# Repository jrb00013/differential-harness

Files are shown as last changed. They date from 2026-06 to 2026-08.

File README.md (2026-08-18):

# differential-harness

**CHORUS-Skid SGH-1 + AEH-1** — full hardware blueprint: **23 OpenSCAD parts**, simulation, DAQ, BOM, test protocol, patent playbook.

## Vision — osmotic-vortex hydro (VOH)

**Master index:** [docs/VISION.md](docs/VISION.md)

| Layer | Doc | Sim |
|---|-----|-----|
| **UDT** — Universal Differential Tink (rays, particle bytes) | [UDT_PHYSICS.md](docs/UDT_PHYSICS.md) | `differential_tink.py` |
| **AOR** — Acoustic-Osmotic Ram (sound + brine + ram pipe) | [AOR_PHYSICS.md](docs/AOR_PHYSICS.md) | `acoustic_osmotic_ram.py` |
| **VOH** — Vortex-Osmotic Hydro / Z-Hydro (spin + z-leg) | [VOH_PHYSICS.md](docs/VOH_PHYSICS.md) | `vortex_osmotic_hydro.py` |

```bash
python -m simulation.experiments   # exports vision_stack (E14–E16) in paper_experiments.json
```

## Bench validation (T0–T1)

```bash
pip install -e ".[dev]"
python -m daq.logger --test T1 --duration 3600          # 1 h CSV → data/bench/
python -m simulation.bench_validation --csv data/bench/T1_*.csv
python scripts/run_test_protocol.py --test T1           # full protocol + auto validation
pytest tests/
```

Notebooks: `notebooks/T1_bench_validation.ipynb`, `notebooks/VOH_spin_breakeven.ipynb`

## Real DAQ ingestion, calibration, geometry audit, dashboard

See [docs/ROADMAP.md](docs/ROADMAP.md) for the full current-state /
roadmap and an honest per-item completion status; execution order is
in [docs/IMPLEMENTATION_PLAN.md](docs/IMPLEMENTATION_PLAN.md).

```bash
# Real serial ingestion (pyserial): opens --port for real, decodes
# checksummed $SGH1/$SGHV frames (daq/protocol.py), falls back to
# simulation ONLY on open/read failure, with a loud repeated warning.
python -m daq.serial_sensors --port /dev/ttyUSB0 --duration 60

# Fit L_p / RPM->torque constants from bench CSVs (labels data
# provenance simulated/real explicitly; never fabricates "real").
python -m scripts.calibrate_constants --csv data/bench/*.csv

# CAD geometry manifold/watertightness check (shells out to `openscad`
# CLI when installed; otherwise records an explicit per-part skip
# reason instead of a silent pass).
python -m scripts.audit_openscad

# Resumable protocol runner: re-enter at the first incomplete step
# instead of restarting from T0 after a crash/disconnect.
python scripts/run_test_protocol.py --test all
python scripts/run_test_protocol.py --test all --resume

# Live dashboard over an active/completed bench CSV (stdlib only).
python -m daq.dashboard --csv data/bench/T1_baseline_20260609_235853.csv
```

Round 2 (see [docs/ROADMAP_ROUND2.md](docs/ROADMAP_ROUND2.md) /
[docs/IMPLEMENTATION_PLAN_ROUND2.md](docs/IMPLEMENTATION_PLAN_ROUND2.md))
adds real vision-stack signal processing, multi-run calibration
statistics, protocol-run history, and STL winding checks:

```bash
# Multi-run L_p calibration with a confidence interval + outlier flags.
python -m scripts.calibrate_constants --csv data/bench/*.csv --aggregate

# Table of every checkpointed protocol run under data/bench/.
python -m scripts.protocol_history
```

`simulation/vision_signal.py` turns a stream of `$SGHV` samples into
RMS amplitude, phase coherence, and an `eta_tink` estimate; see its
module docstring for the underlying math.

Round 3 (see [docs/ROADMAP_ROUND3.md](docs/ROADMAP_ROUND3.md) /
[docs/IMPLEMENTATION_PLAN_ROUND3.md](docs/IMPLEMENTATION_PLAN_ROUND3.md))
turns outward: real economics, real candidate sites, environmental
framing, and a fouling test protocol.

```bash
# Real LCOE estimate + full optimistic/conservative sensitivity sweep.
python -m scripts.lcoe_model --power-w 1000 --density-w-m2 8
python -m scripts.lcoe_model --sensitivity

# Fouling flux-decline check: fits L_p in chronological sub-windows of
# one bench run and reports percent permeability decline.
python -m scripts.calibrate_constants --csv data/bench/T1_baseline_*.csv --time-series
```

See [docs/ECONOMICS.md](docs/ECONOMICS.md) for the honest LCOE
writeup (not cost-competitive with solar/wind/storage today, and why),
[docs/CANDIDATE_SITES.md](docs/CANDIDATE_SITES.md) for real desalination-
outfall and estuary site data, [docs/ENVIRONMENTAL_IMPACT.md](docs/ENVIRONMENTAL_IMPACT.md)
for brine-discharge ecology and regulatory precedent, and
[docs/FOULING_TEST_PROTOCOL.md](docs/FOULING_TEST_PROTOCOL.md) for the
T1f fouling-resistance test phase.

Round 4 (see [docs/ROADMAP_ROUND4.md](docs/ROADMAP_ROUND4.md)) attacks
round 3's cost gap directly: breakeven sensitivity, a manufacturing
learning-curve projection, and an avoided-cost co-benefit credit.

```bash
# What single parameter (density/membrane cost/membrane life) would
# need to change, and by how much, to hit a target LCOE?
python -m scripts.lcoe_model --breakeven 0.09 --power-w 1000

# Cost at 10x/100x/1000x manufacturing volume (Wright's law).
python -m scripts.lcoe_model --learning-curve

# Apply the real, cited avoided-transmission-and-distribution credit.
python -m scripts.lcoe_model --power-w 1000 --co-benefit
```

Honest bottom line (full detail in `docs/ECONOMICS.md`): no single
lever closes the gap to solar/wind, and manufacturing scale alone
doesn't either — only stacking lab-grade power density AND 1000x
production volume simultaneously reaches battery-storage-adjacent
economics (~$0.30/kWh), not solar/wind directly.

## Research paper (PoC)

**Joseph Black** and **Connor White** — *CHORUS-SGH-1: Brine-Gradient Power, UDT/AOR/VOH Vision, and Osmotic-Vortex Hydro* ([PDF](papers/Black_2026_CHORUS_SGH1_PoC.pdf) · [source](papers/black_2026_chorus_sgh1_poc.md))

```bash
pip install -e ".[paper]"
python -m simulation.experiments      # exports/paper_experiments.json
python scripts/generate_paper_figures.py  # exports/figures/*.png
python scripts/build_research_paper.py  # papers/Black_2026_CHORUS_SGH1_PoC.pdf (~20+ pages with figures)
```

Math supplements: [docs/math/](docs/math/) · **Real-world anchors:** [REAL_WORLD_DATA.md](docs/math/REAL_WORLD_DATA.md) (Statkraft, Perth, Trapani, 6.3 W/m² PRO)

```bash
./scripts/run_paper_pipeline.sh   # experiments + calibration + figures + PDF

# Or from pdf-genesis (uses .pdf-genesis/manifest.json):
pdf-genesis repo .                  # full pipeline + Black_2026 PDF
pdf-genesis repo . --mode compile   # markdown compendium only
```

## One command

```bash
cd ~/projects/differential-harness
python3 -m venv .venv && source .venv/bin/activate && pip install -e .
chmod +x scripts/build_all.sh hardware/scripts/export_stl.sh
./scripts/build_all.sh
```

Requires [OpenSCAD](https://openscad.org/) for STL export: `sudo apt install openscad`

## What you get

| Category | Count | Location |
|---|---|---|
| **OpenSCAD parts** | 23 | [hardware/openscad/](hardware/openscad/) |
| **STL exports** | 23 | [hardware/stl/](hardware/stl/) after export |
| **Docs** | 12+ | [docs/](docs/), [hardware/BUILD_BLUEPRINT.md](hardware/BUILD_BLUEPRINT.md) |
| **BOM lines** | 35+ | [hardware/bom/SGH1_BOM.csv](hardware/bom/SGH1_BOM.csv) |
| **Python sim** | 9+ modules | [simulation/](simulation/) |
| **Vision docs** | 4 | [docs/VISION.md](docs/VISION.md) |
| **DAQ** | 3 scripts | [daq/](daq/) |
| **Notebooks** | 2 | [notebooks/](notebooks/) |

## CAD part list

**PRO path:** membrane_housing, membrane_plate, end_cap, manifolds (feed/draw), pressure_ring, px_module, turbine_housing, relief_valve_block  

**CHORUS/AEH:** skid_enclosure, aeh_panel, us_mount_ring  

**Structure:** skid_frame, drip_tray, mount_rail, pump_mount, sensor_bracket  

**Utilities:** feed/brine tank adapters, flange_adapter  

**v2:** red_cartridge_v2  

**Assemblies:** sgh1_assembly, sgh1_exploded_assembly  

Index: [hardware/COMPONENT_INDEX.md](hardware/COMPONENT_INDEX.md)  
Dimensions: [hardware/DRAWINGS_DIMENSIONS.md](hardware/DRAWINGS_DIMENSIONS.md) (auto-generated)

## PDF report

```bash
cd ~/projects/pdf-genesis && pip install -e .
pdf-genesis build ../differential-harness/exports/sgh1_design.json \
  -o ../differential-harness/exports/SGH1_Design_Report.pdf
```

## Wiring & test

- [hardware/electrical/WIRING.md](hardware/electrical/WIRING.md)
- [docs/SGH1_TEST_PROTOCOL.md](docs/SGH1_TEST_PROTOCOL.md)
- [docs/SGH1_PATENT_AND_DEPLOYMENT.md](docs/SGH1_PATENT_AND_DEPLOYMENT.md)

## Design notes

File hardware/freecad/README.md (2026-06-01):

# FreeCAD assembly

1. Install FreeCAD.
2. Import all STL from `../stl/` (after `hardware/scripts/export_stl.sh`).
3. Save assembly as `SGH1_Assembly.FCStd`.
4. TechDraw → export PDF drawings to `exports/drawings/`.

OpenSCAD sources remain parametric master; FreeCAD is for constraints and shop drawings.

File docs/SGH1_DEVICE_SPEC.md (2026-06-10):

# SGH-1 Device Specification (CHORUS-Skid PRO Core)

## 1. Purpose

Extract net energy from a **salinity gradient** between high-salinity draw (desal brine simulant) and low-salinity feed (treated wastewater / river water class), mounted on a **CHORUS** frame with ports for thermal/moist (CHOR) and acoustic (AEH) subsystems.

## 2. Functional requirements

| ID | Requirement |
|----|---|
| FR-1 | Steady operation at ΔP ≈ 0.4–0.6 × Δπ |
| FR-2 | Feed side ≤ 10 bar gauge; draw side rated per `delta_P_star_bar` in sizing export |
| FR-3 | Continuous logging: P, Q, conductivity ×2, temperature ×2 |
| FR-4 | Leak containment: skid drip tray, brine-resistant materials |
| FR-5 | Modular membrane cartridge removable without draining both tanks |

## 3. Performance targets (50 W design point)

Generated by `python simulation/run_sizing.py --power 50`. Values in `exports/sgh1_sizing.json`.

## 4. P&ID (logical)

```
[Low-sal tank] → [Feed pump] → [Prefilter] → [Feed manifold]
      → [Membrane stack: feed | membrane | draw] → [Draw manifold]
      → [PX / throttle] → [Turbine or motor load] → [Brine return tank]
```

AEH: urban/traffic-facing panel → rectifier → DAQ power bus (supplemental).  
US transducer: feed manifold (CP enhancement, optional).

## 5. Safety

- Rupture disk on draw: 1.2 × ΔP*
- Eye wash for brine splash
- No pressure test with glass components
- Electrical GFCI on pump/DAQ

## 6. Interfaces

| Port | Size | Notes |
|---|---|---|
| Feed inlet | 1/2 FNPT | Low salinity |
| Draw brine out | 3/4 FNPT | To return tank |
| Draw high-pressure | 1 FNPT | To PX/turbine |
| Sensor | 1/4 NPT | Pressure, temp |
| Conductivity | 3/4" compression | Feed + draw |

## 7. v2

- RED nanopore cartridge, same bolt pattern
- Full moist-electric panel on CHOR plenum

## 8. v3 — UDT / AOR / VOH (vision)

See [VISION.md](VISION.md).

| Module | Hardware target |
|---|---|
| UDT | `chorus_aeh_panel`, `sgh1_us_mount_ring`, planned `sgh1_tink_ring` |
| AOR | Resonant enclosure + draw ram leg (`sgh1_z_pipe` planned) |
| VOH | Spinning membrane drum + axial z-leg; `sgh1_vortex_basin` planned |

Validation: T1b (UDT), T1c (VOH) per [SGH1_TEST_PROTOCOL.md](SGH1_TEST_PROTOCOL.md).

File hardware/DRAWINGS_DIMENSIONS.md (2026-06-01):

# SGH-1 Dimensioned Drawing Table (auto-generated)

| Parameter | Value | Unit |
|---|---|---|
| Target power | 10.0 | W |
| Membrane area (total) | 0.7200 | m² |
| Active plate | 200.0 × 300.0 | mm |
| Plate count | 12 | — |
| Housing OD × length | 280.0 × 264 | mm |
| Bolt circle | 240.0 | mm |
| Skid frame L × W × H | 664 × 480.0 × 900 | mm |
| Δπ | 6.916 | MPa |
| ΔP* (operating) | 34.58 | bar |
| Feed flow (sim) | 0.149 | L/min |
| c_draw / c_feed | 1400.0 / 5.0 | mol/m³ |

## Tolerances (shop)

| Feature | Tolerance |
|---|---|
| Housing bore | +0.2 / -0.0 mm |
| O-ring groove | per AS568 dash |
| Manifold ports | NPT thread class |
| Frame extrusion cut | ±1 mm |

## OpenSCAD → STL

See `hardware/scripts/export_stl.sh`.

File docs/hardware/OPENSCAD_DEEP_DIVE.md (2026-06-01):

# OpenSCAD Deep Dive — CHORUS-Skid SGH-1

Auto-audit: `python scripts/audit_openscad.py` → `exports/openscad_audit.json`

## Design pipeline

```
simulation/run_sizing.py  →  exports/sgh1_sizing.json
                         →  hardware/openscad/lib/generated_constants.scad
                         →  all part .scad files
hardware/scripts/export_stl.sh  →  hardware/stl/*.stl
```

## Generated constants (single source of truth)

| Variable | Meaning |
|---|---|
| `P_target_W` | Design electrical target |
| `A_mem_m2` | Total active membrane area |
| `active_w`, `active_h` | Plate window (mm) |
| `n_plates` | Stack count (CAD cap 12) |
| `housing_od`, `housing_len` | Cylinder shell |
| `bolt_circle` | Flange bolt pattern |
| `frame_L`, `frame_W`, `frame_H` | Skid envelope |
| `delta_P_bar` | Kim–Baker operating pressure |
| `plate_pitch` | Axial spacing per cell |

## PRO fluid path (PRO-01 … PRO-09)

| File | Function |
|---|---|
| `sgh1_membrane_housing.scad` | Cylinder shell, plate rails, sensor slot |
| `sgh1_membrane_plate.scad` | Spacer/window per cell |
| `sgh1_end_cap.scad` | Feed and draw end closures |
| `sgh1_pressure_vessel_ring.scad` | Compress ring |
| `sgh1_manifold_feed.scad` | Low-sal distribution |
| `sgh1_manifold_draw.scad` | High-pressure brine header |
| `sgh1_px_module.scad` | Pressure exchanger body |
| `sgh1_turbine_housing.scad` | Hydraulic test load mount |
| `sgh1_relief_valve_block.scad` | 1.2× ΔP* safety |

**Housing stack length:** `n_plates × plate_pitch + 40` mm (end allowances).

## CHORUS / AEH (CHOR-01, AEH-01, AEH-02)

| File | Function |
|---|---|
| `chorus_skid_enclosure.scad` | Moist/thermal plenum around stack |
| `chorus_aeh_panel.scad` | 6×4 Helmholtz cells, piezo pockets, US mount |
| `sgh1_us_mount_ring.scad` | Clamps 28 kHz transducer to feed path |

**AEH panel (derived):** width ≈ 0.6 × frame_W (288 mm), height 400 mm, thickness 28 mm,  
24 resonators (neck 8 mm, cavity 35 mm).

## Structure & utilities

`sgh1_skid_frame.scad`, `sgh1_drip_tray.scad`, `sgh1_mount_rail.scad`,  
`sgh1_pump_mount.scad`, `sgh1_sensor_bracket.scad`, tank adapters, `sgh1_flange_adapter.scad`.

## Assemblies

- `sgh1_assembly.scad` — installed layout for review  
- `sgh1_exploded_assembly.scad` — documentation exploded view  
- `sgh1_red_cartridge_v2.scad` — swap-in RED stack (v2)

## Export

```bash
sudo apt install openscad   # if needed
bash hardware/scripts/export_stl.sh
```

## Tolerances

See `hardware/DRAWINGS_DIMENSIONS.md` — housing bore +0.2/−0.0 mm, NPT manifolds, frame ±1 mm.

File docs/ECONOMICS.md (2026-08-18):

# CHORUS-SGH-1 Economics — LCOE Model and Honest Competitiveness Assessment

This document grounds a real levelized-cost-of-energy (LCOE) estimate
for CHORUS-SGH-1 in the cost anchors already in this repo
(`hardware/bom/SGH1_BOM.csv`, `docs/math/REAL_WORLD_DATA.md`) plus the
existing PRO physics simulation (`simulation.pro_cycle`,
`simulation.parasitics`), computed by `scripts/lcoe_model.py`. It is
written to be honest, not promotional: **the numbers below show this
technology is not currently cost-competitive with solar, wind, or
battery storage at any power density this repo's simulation can
substantiate**, and that is treated as a real finding, not a defect in
the writeup. Round 4 (below) goes further and asks whether any
combination of parameters, manufacturing scale, or reframing closes
that gap — the honest answer is "not with any single lever, and only
approaches battery-storage-adjacent economics (not solar/wind) under
two simultaneous, currently-unproven extremes."

## Model summary

`scripts/lcoe_model.py::compute_lcoe()`:

1. Required membrane area = target power / assumed areal power density
   (W/m²).
2. `simulation.sizing.size_skid` caps a single skid unit's CAD at 12
   membrane plates (~0.72 m²) — a target beyond that is modeled as N
   identical parallel skid units, not one skid with unrealistically
   large membrane area.
3. Capital cost = balance-of-plant (BOP) cost per skid unit (from the
   BOM's own estimate line, `EST-001`, "~$2,500-8,000 excl. membrane
   OEM") × N units, plus membrane cost (area × $/m²).
4. Capital is annualized with a standard capital recovery factor (CRF)
   at a 7% discount rate over a 20-year project life; membrane capital
   is annualized separately over its own (shorter) replacement life,
   since replacing a membrane is a recurring capital expenditure, not
   simple opex.
5. Net energy uses a parasitic-loss derate taken from
   `simulation.parasitics.skid_energy_balance` (pump power, PX
   recovery credit) at a reference skid state, applied to the assumed
   gross areal power. See the caveat below — this derate currently
   floors at 0% because the bench-scale PX recovery credit formula in
   `simulation/parasitics.py` is explicitly documented there as
   "illustrative," not calibrated, and at these small W-scale bench
   numbers it can exceed the pump load. That is a real model
   limitation, not a claim of zero parasitic loss at any real scale.

## Cost anchors used (all sourced, not invented)

| Anchor | Value | Source |
|---|---|---|
| Balance-of-plant cost per skid unit | $2,500 (optimistic) – $8,000 (conservative) | `hardware/bom/SGH1_BOM.csv`, line `EST-001`, "excl. membrane OEM" |
| Membrane cost | $30/m² (optimistic) – $150/m² (conservative) | `docs/math/REAL_WORLD_DATA.md` ($4-150/m² range); a 2024 Frontiers in Energy Research PRO-SWRO techno-economic analysis cites commercial PRO-membrane-provider quotes of **$9.2-12.3/m²**; a real commercial SWRO element (LG Chem SW 400 R, 37 m² active area) retails at **~$21/m²** (wateranywhere.com) as an upper-bound analog since PRO/FO specialty sheets are less commoditized than standard SWRO |
| Membrane replacement interval | 5 (conservative) – 7 (optimistic) years | RO/FO industry maintenance guidance puts commercial membrane life at 3-5 years (Morui); PRO-specific figures were not found publicly — treated as an assumption pending real fouling data, see `docs/FOULING_TEST_PROTOCOL.md` |
| Power density scenarios | 1 W/m² (Statkraft Tofte pilot floor) / 8 W/m² (practical large-scale) / 25 W/m² (lab hypersaline ceiling) | `docs/math/REAL_WORLD_DATA.md` |

## Results (`scripts/lcoe_model.py --sensitivity`)

| Power-density scenario | Cost scenario | Area needed (m², 1 kW target) | LCOE ($/kWh) |
|---|---|---|---|
| Lab optimistic (25 W/m²) | Optimistic cost | 2.16 | **$2.05** |
| Lab optimistic (25 W/m²) | Conservative cost | 2.16 | **$6.65** |
| Practical (8 W/m²) | Optimistic cost | 6.48 | **$6.40** |
| Practical (8 W/m²) | Conservative cost | 6.48 | **$20.78** |
| Statkraft-floor (1 W/m²) | Optimistic cost | 50.4 | **$51.16** |
| Statkraft-floor (1 W/m²) | Conservative cost | 50.4 | **$166.24** |

(Full sweep: `python -m scripts.lcoe_model --sensitivity`.)

## Honest comparison against real benchmarks

From Lazard's LCOE+ report (June 2024, the standard industry reference):

| Technology | LCOE ($/kWh) |
|---|---|
| Utility-scale solar PV (standalone) | **$0.029 – $0.092** (midpoint ~$0.061) |
| Onshore wind (standalone) | **$0.027 – $0.073** (midpoint ~$0.050) |
| Solar + storage | $0.060 – $0.210 |
| Standalone battery storage (100MW/4hr) | $0.124 – $0.296 |

**Even CHORUS-SGH-1's best-case scenario ($2.05/kWh, requiring both a
lab-grade 25 W/m² power density this repo has not validated on real
hardware and optimistic membrane/BOP costs) is ~22-75x more expensive
than solar or wind, and ~7-33x more expensive than standalone battery
storage.** The practical-density scenario (8 W/m², the literature's
"practical large-scale" anchor) is $6.40-$20.78/kWh — 70-750x solar.
The Statkraft-floor scenario, which is what an unimproved real-world
pilot actually achieved in 2009-2013, is $51-$166/kWh — in the range
that led Statkraft to shut the Tofte pilot down in 2014, stating PRO
"would not be competitive with other renewable energy technologies
within the foreseeable future" (POWER Magazine, ForwardOsmosisTech).

**This is not competitive today, and this document says so plainly.**
The honest, useful information here is not "CHORUS-SGH-1 is cheap" but:

1. **Power density is the entire game.** Moving from the Statkraft
   floor (1 W/m²) to the lab ceiling (25 W/m²) closes nearly the whole
   gap between "hopeless" and "merely 20-75x too expensive" — this
   repo's own UDT/AOR/VOH vision-stack work (`docs/UDT_PHYSICS.md`,
   `simulation/differential_tink.py`) exists specifically because
   raising *effective* membrane power density (concentration-
   polarization mitigation via acoustic/vortex actuation) is the only
   lever big enough to matter economically, not a side experiment.
2. **BOP cost dominates over membrane cost at small scale** (compare
   the $/kWh spread across cost scenarios above): at bench/pilot scale,
   fixed per-unit balance-of-plant cost (frame, pumps, sensors, DAQ)
   swamps the membrane's own $/m², meaning larger single-unit skids
   (fewer, bigger units instead of many small ones) is a real cost
   lever this repo's CAD (`hardware/openscad/`) does not yet target —
   the 12-plate bench cap in `simulation/sizing.py` exists for CAD
   printability reasons, not economic ones.
3. **This is a niche co-location technology, not a general
   solar/wind replacement.** The honest framing (see
   `docs/CANDIDATE_SITES.md`) is: CHORUS-SGH-1 only makes any
   economic sense at all where a salinity-gradient feed pair *already
   exists as a waste stream* (a desalination brine outfall, for
   example), because the "fuel" (concentration difference) is free and
   already flowing — the LCOE fight here is purely about capex and
   parasitics on a stream that would otherwise be discharged
   unused, not about competing for siting against solar/wind on
   cost-of-energy alone.

## Round 4 — attacking the gap directly

Round 3 found the gap; round 4 asks whether any real combination of
parameters, manufacturing scale, or reframing closes it.
`scripts/lcoe_model.py` gained `breakeven_report()`,
`volume_cost_projection()`, and `co_benefit_adjusted_lcoe()` to answer
this with real code, not narrative optimism.

### R4.1 — Breakeven sensitivity: is there a single-lever path?

`scripts/lcoe_model.py::breakeven_report(target_lcoe, ...)` bisects for
the value of power density, membrane cost, or membrane replacement life
that would be needed to hit a target LCOE, holding everything else at
its default (conservative-cost) value, then checks the solved value
against a real ceiling (60 W/m² lab-hypersaline density, $0/m² cost
floor, 15-year industrial RO/FO membrane life):

```
$ python -m scripts.lcoe_model --breakeven 0.09 --power-w 1000
```

**Result: reaching Lazard's solar/wind upper bound ($0.09/kWh) is
UNREACHABLE via any single lever.** Power density would need to exceed
240 W/m² (4x the highest lab-reported PRO density in the literature).
Membrane cost would need to go negative. Membrane life would need to
exceed 150 years. None of these are physically meaningful — **there is
no single-parameter path to solar/wind competitiveness.**

Even stacking every optimistic lever simultaneously (60 W/m² lab
ceiling, a free membrane, a 15-year life, and the cheapest BOP
scenario) at once:

```python
>>> compute_lcoe(P_target_W=1000, P_density_W_m2=60.0,
...     membrane_cost_usd_m2=0.0, membrane_life_years=15.0,
...     bop_cost_usd_per_skid=2500.0).lcoe_usd_per_kWh
0.84
```

**$0.84/kWh — still ~9-28x above solar/wind, even in a scenario that
requires simultaneously exceeding the highest lab-reported power
density AND a free membrane.** This confirms round 3's framing:
capital cost (specifically BOP capex — frame, pumps, sensors, DAQ) is
the dominant term, not membrane cost, and no single lever closes it.

### R4.2 — Manufacturing scale: does volume help?

`scripts/lcoe_model.py::volume_cost_projection()` applies a Wright's-law
learning curve (cost declines a constant % per doubling of cumulative
units produced) to this repo's own BOM baseline, across three cited
learning-rate scenarios (10% conservative/simple-hardware analog, 15%
Wright's original 1936 aircraft-manufacturing rate, 20% solar PV's
sustained real-world rate — no PRO/FO-membrane- or small-batch-BOP-
specific learning rate exists in the public literature, stated plainly
rather than invented):

```
$ python -m scripts.lcoe_model --learning-curve
```

| Volume | Learning rate | BOP cost/skid | LCOE @ practical density (8 W/m²) |
|---|---|---|---|
| 1x (today) | — | $8,000 | $20.78/kWh |
| 1000x | 10% conservative | $2,800 | $7.27/kWh |
| 1000x | 15% typical | $1,584 | $4.11/kWh |
| 1000x | 20% solar-analog | $866 | $2.25/kWh |

**Even at 1000x cumulative manufacturing volume and the most optimistic
(solar-analog) learning rate, at PRACTICAL power density, LCOE stays at
$2.25/kWh — manufacturing scale ALONE does not close the gap either.**
Only combining 1000x volume with lab-hypersaline density (60 W/m²)
approaches order-of-magnitude parity with standalone battery storage:

```python
>>> compute_lcoe(P_target_W=1000, P_density_W_m2=60.0,
...     bop_cost_usd_per_skid=865.6, membrane_cost_usd_m2=16.2,
...     membrane_life_years=15.0).lcoe_usd_per_kWh
0.295
```

**$0.295/kWh — within Lazard's standalone battery storage range
($0.124-0.296/kWh), but still 3-10x above solar/wind directly.** This
requires validating two separate, extreme, currently-unproven
assumptions at once (lab-grade power density AND 1000x manufacturing
scale), neither of which this repo's own T0-T2 protocol has confirmed
achievable on real hardware.

### R4.3 — Value beyond raw $/kWh: is there a co-benefit case?

Two distinct arguments were tested, honestly, for whether the raw
$/kWh comparison is even the right frame:

1. **"The brine is already flowing, so fuel is free."** True, but
   **this is already fully reflected in `compute_lcoe()`** — there has
   never been a fuel-cost line item anywhere in the model, because the
   concentration-gradient "fuel" genuinely costs nothing. This
   argument does not provide an *additional* credit beyond what's
   already modeled; it only explains why capex and power density are
   the entire economic story, which is exactly what R4.1/R4.2 above
   attack. Counting it a second time as a "co-benefit" would be
   double-counting.
2. **Avoided transmission & distribution (T&D) cost.** A generator
   co-located at the point of use (a desalination brine outfall, a
   coastal WWTP) genuinely avoids the T&D infrastructure cost a
   grid-delivered kWh carries. Real utility avoided-cost studies
   quantify this at **~$0.02/kWh** (one CPUC-referenced analysis found
   avoided transmission (1.34¢/kWh) + avoided distribution (0.52¢/kWh)
   = "at least 2.02¢/kWh"). `scripts/lcoe_model.py::co_benefit_adjusted_lcoe()`
   applies this as a real, cited credit:

```
$ python -m scripts.lcoe_model --power-w 1000 --co-benefit
```

**Result: at CHORUS-SGH-1's actual multi-dollar/kWh LCOE scale, this
real credit offsets well under 1% of the raw number** (e.g. $20.78/kWh
→ $20.76/kWh). It is real and worth stating, but it is not remotely
large enough to matter at today's cost structure — it would only start
to matter at an LCOE already close to competitive, which round 4's own
best-case combined scenario ($0.295/kWh) is the closest this analysis
gets to.

### Round 4 bottom line

**No single lever, and no combination of realistic (non-simultaneous-
extreme) levers, closes the gap to solar or wind. A combination of two
simultaneous, currently-unvalidated extremes — lab-hypersaline power
density (60 W/m², never demonstrated outside non-representative lab
conditions per the literature this repo has anchored) AND 1000x
manufacturing scale at a solar-like learning rate (never demonstrated
for this hardware class at all) — gets CHORUS-SGH-1 into the same
order of magnitude as standalone battery storage, not solar/wind
generation directly.** This is the honest answer round 4 was asked to
find: not "here's a plausible path to competitiveness," and not
"the physics fundamentally caps this at any scale" either — it is
"closing this gap requires two separate, extreme, currently-unproven
technical achievements simultaneously, and even then only reaches
battery-storage-adjacent economics, not general renewable-generation
economics." Anything short of both of those simultaneous achievements
leaves this a niche, waste-stream-co-location technology exactly as
round 3 concluded, not a general power-generation competitor.

## Known model limitations (stated, not hidden)

- The parasitic-loss derate currently floors at 0% because
  `simulation/parasitics.py::px_recovery_credit_W` is explicitly
  documented as "illustrative" and is not calibrated against real
  pressure-exchanger hardware — at bench-scale wattages it can exceed
  the pump load, which is not physically meaningful at any real
  deployment scale. Real T1c-scale bench data (`docs/ROADMAP.md` M6)
  is required before this derate can be trusted quantitatively.
- No O&M labor cost is modeled beyond a flat 2%/year of capex
  rule-of-thumb; a real pilot's O&M (especially cleaning-in-place for
  fouling, see `docs/FOULING_TEST_PROTOCOL.md`) could be materially
  higher.
- Membrane replacement interval (5-7 years) is an RO/FO industry
  analog, not a PRO-specific or CHORUS-SGH-1-specific measurement —
  PRO fouling is generally understood in the literature to be worse
  than RO (see `docs/FOULING_TEST_PROTOCOL.md`), so this may be
  optimistic.
- Capacity factor is assumed at 90% (a continuously-fed brine/estuary
  stream, unlike solar's ~25% or wind's ~35%) but this has not been
  validated against any real operating data — biofouling-driven
  downtime (again, see `docs/FOULING_TEST_PROTOCOL.md`) could reduce
  it substantially.

## Sources

- Lazard, *LCOE+ Report*, June 2024 — https://www.lazard.com/media/xemfey0k/lazards-lcoeplus-june-2024-_vf.pdf
- pv magazine, "Lazard says fossil fuel costs double that of utility-scale solar," June 2024 — https://www.pv-magazine.com/2024/06/12/lazard-says-fossil-fuel-costs-double-that-of-utility-scale-solar/
- POWER Magazine, "Statkraft Shelves Osmotic Power Project" — https://www.powermag.com/statkraft-shelves-osmotic-power-project/
- ForwardOsmosisTech, "Is PRO economically feasible? Not according to Statkraft" — https://www.forwardosmosistech.com/statkraft-discontinues-investments-in-pressure-retarded-osmosis-2/
- Frontiers in Energy Research, "Techno-economic analysis of a PRO-SWRO hybrid," 2024 — https://www.frontiersin.org/journals/energy-research/articles/10.3389/fenrg.2024.1448402/full
- WaterAnywhere, LG Chem SW 400 R SWRO element listing — https://wateranywhere.com/products/8x40-seawater-9-000-gpd-800-psi-99-85-rej-400-ft2-lg-chem-ro-membrane
- Morui, "Typical operating costs and lifespan of industrial RO membranes" — https://www.moruiwater.com/knowledge/typical-operating-costs-and-lifespan-of-industrial-ro-membranes
- Our World in Data, "Learning curves: What does it mean for a technology to follow Wright's Law?" — https://ourworldindata.org/learning-curve
- Metavert, "Wright's Law" (solar PV ~20% learning rate over 4+ decades; Wright's original ~15% aircraft-manufacturing rate) — https://metavert.io/wrights-law
- CPUC, T&D avoided-cost study webinar slide deck (avoided transmission 1.34¢/kWh + avoided distribution 0.52¢/kWh) — https://www.cpuc.ca.gov/-/media/cpuc-website/divisions/energy-division/documents/energy-efficiency/ider-cost-effectiveness/td-study-webinar-slide-deck.pdf
- Demand Side Analytics, "Pennsylvania Transmission and Distribution (T&D) Avoided Cost Study" — https://demandsideanalytics.com/pennsylvania-transmission-and-distribution-td-avoided-cost-study/
- `docs/math/REAL_WORLD_DATA.md` (this repo) and its own references list.

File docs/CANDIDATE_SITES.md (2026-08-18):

# CHORUS-SGH-1 Candidate Deployment Sites

`docs/ECONOMICS.md` concludes CHORUS-SGH-1 only makes economic sense
where a salinity-gradient feed pair already exists as a waste/byproduct
stream — the "fuel" (concentration difference) must be free and already
flowing, because the technology cannot win a cost-of-energy fight
against solar/wind on its own. This document grounds that claim in real,
publicly documented site types with real salinity/flow figures, rather
than a generic "co-locate at a desalination plant" thought experiment.

## Site type 1 — Large SWRO desalination brine outfall: Perth Seawater Desalination Plant, Australia

- Combined Stage 1 + Stage 2 (PSDP1+2) brine discharge ≈ **418 ML/day**
  (~418,000 m³/day); Stage 1 alone discharges at ~2.19 m³/s.
- Brine salinity ≈ **1.8× ambient seawater** — ambient Indian Ocean
  seawater off Perth ~35 g/L (consistent with `docs/math/REAL_WORLD_DATA.md`'s
  "Perth 36-39 g/L" seawater anchor), brine ~63 g/L.
- Outfall: 1.6 m diameter pipe extending 500 m offshore, multi-port
  diffuser angled 60°, licensed for a 45× dilution factor by 50 m from
  the diffuser.
- **Fit for CHORUS-SGH-1**: this is the closest real-world match to the
  repo's own default salinity pair (`C_BRINE_8PCT` ≈ 1400 mol/m³ /
  `C_TREATED_WW` ≈ 5 mol/m³ in `simulation/constants.py`, noted there as
  "conservative-high brine vs. Perth operational ~1200/35 mixing
  pair"). A CHORUS-SGH-1 skid could intercept a slipstream of the
  pre-diffuser brine and mix it with an available lower-salinity stream
  (e.g. treated effluent, harbor water) before it re-enters the outfall
  — recovering some energy from a concentration gradient that is
  otherwise dissipated for free in the diffuser's dilution zone.
- Sources: [Numerical simulations of brine dispersion, PSDP2 (IAHR)](https://static.iahr.org/34/122.pdf), [PSDP2 Environmental Referral Document (WA EPA)](https://www.epa.wa.gov.au/sites/default/files/Referral_Documentation/2.%20PSDP2_Environmental_Referral_Document_Part%20A.pdf)

## Site type 2 — Large SWRO desalination brine outfall: Carlsbad Desalination Plant, California

- Produces 50 MGD (≈189,250 m³/day) of product water and 50 MGD
  (≈189,250 m³/day) of brine concentrate at **~67,000 ppm TSS (~67
  g/L)**, roughly 2× incoming seawater salinity — before the plant's
  own required pre-discharge dilution with intake seawater (up to a
  combined 238 MGD / ~901,000 m³/day permitted discharge scenario, at a
  target diluted salinity of ~42 ppt).
- Documented plume behavior: even after dilution, the discharge plume
  has been observed extending ~600 m offshore with salinity up to 2.7
  units above the ~33.2 ppt ambient baseline — i.e. real, measured
  evidence that dilution capacity is a genuine engineering/permitting
  constraint at this site, not a theoretical concern (see
  `docs/ENVIRONMENTAL_IMPACT.md`).
- **Fit for CHORUS-SGH-1**: structurally identical opportunity to
  Perth — a co-located skid could use some of the plant's own required
  dilution water flow as the low-salinity draw stream, extracting PRO
  power from a mixing step the plant must perform anyway for permit
  compliance.
- Sources: [Biological and Physical Effects of Brine Discharge from Carlsbad (MDPI Water, 2019)](https://www.mdpi.com/2073-4441/11/2/208), [San Diego County Water Authority — Seawater Desalination](https://www.sdcwa.org/your-water/local-water-supplies/seawater-desalination/), [CA Water Boards — Carlsbad Desalination Plant regulatory page](https://www.waterboards.ca.gov/sandiego/water_issues/programs/regulatory/carlsbad_desalination.html)

## Site type 3 — River-mouth/fjord estuary gradient: Statkraft Tofte pilot site, Oslo Fjord, Norway

- The only real-world PRO pilot at meaningful scale to date (2,000 m²
  membrane, opened Nov 2009, shelved Jan 2014): fed by Tofte River
  freshwater against Oslo Fjord seawater, using ~120 m equivalent
  water-column pressure across 66 pressure pipes, producing only 2-4
  kW — a realized power density of **~1-2 W/m²**, far below the ~5
  W/m² industry viability threshold.
- **Honest gap**: this research pass could not independently confirm a
  specific Oslo Fjord salinity (ppt) figure — Oslo Fjord is a
  brackish-influenced estuary and its salinity is very likely below
  open-ocean 35 g/L, but that number is not asserted here without a
  verified source. This is flagged explicitly rather than filled in
  with an invented figure.
- **Fit for CHORUS-SGH-1**: this is the real-world proof that a
  river/fjord-mouth site is a valid site *type*, but also the
  strongest cautionary data point in `docs/ECONOMICS.md` and
  `docs/FOULING_TEST_PROTOCOL.md` — the Tofte pilot's failure to reach
  economic power density, compounded by fouling from real (not clean
  bench) water, is exactly the failure mode this repo's protocol work
  is trying to test for before committing to a real site.
- Sources: [Statkraft osmotic power prototype in Hurum (Wikipedia)](https://en.wikipedia.org/wiki/Statkraft_osmotic_power_prototype_in_Hurum), [POWER Magazine — Norway Inaugurates Osmotic Power Plant](https://www.powermag.com/norway-inaugurates-osmotic-power-plant/), [POWER Magazine — Statkraft Shelves Osmotic Power Project](https://www.powermag.com/statkraft-shelves-osmotic-power-project/)

## Site type 4 — Generic SWRO brine concentrate class (WaterReuse white paper anchor)

Already cited in this repo's `docs/math/REAL_WORLD_DATA.md`: the
WaterReuse Association's Seawater Concentrate White Paper documents
SWRO brine reject in the **52-70 g/L** range (1.5-2× seawater), which
is the general class both Perth and Carlsbad fall into. This matters
as a *class*, separate from the two named sites above, because it is
the basis for treating "co-locate at essentially any SWRO desalination
plant's brine outfall" as a broadly repeatable site type across many
facilities worldwide, not a one-off opportunity limited to Perth or
Carlsbad specifically. Source (already referenced in this repo): [1]
in `docs/math/REAL_WORLD_DATA.md`'s references list.

## Site type 5 — Municipal WWTP effluent into saline receiving water (identified, NOT independently verified — honest gap)

A coastal municipal wastewater treatment plant discharging treated
effluent into an estuary or harbor is a structurally plausible fourth
site *type* (treated effluent is a real, continuously-flowing
low-salinity stream analogous to `C_TREATED_WW` in
`simulation/constants.py`, and many coastal cities operate exactly this
kind of outfall). **This research pass did not find a specific real
plant's effluent salinity/flow figures to cite**, and rather than
fabricate a plausible-sounding number, this is recorded as an open
research gap: a real round-4 task would be to identify one specific
coastal WWTP with public NPDES/discharge-permit flow and salinity data
and confirm whether its effluent quality/flow profile is compatible
with `simulation/constants.py`'s `C_TREATED_WW` anchor before treating
it as a real candidate site rather than a plausible site *type*.

## What this means for siting priority

Sites 1 and 2 (Perth, Carlsbad) are the strongest real candidates:
large, continuous, well-characterized brine flows with public
environmental-monitoring data already available (useful for both
`docs/ECONOMICS.md` capacity-factor assumptions and
`docs/ENVIRONMENTAL_IMPACT.md` permitting precedent). Site 3
(Statkraft Tofte) is the cautionary real-world benchmark this whole
roadmap is implicitly trying to beat. Site 4 is the general
repeatable-class argument. Site 5 is honestly flagged as unverified
rather than invented.

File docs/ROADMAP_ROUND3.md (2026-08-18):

# Round 3 Roadmap — Economics, Siting, Environmental, and Fouling

Round 1 (PR #1) built real DAQ/protocol/calibration/geometry-audit
infrastructure. Round 2 (PR #2) added vision-stack signal processing,
dashboard hardening, multi-run calibration statistics, protocol
history, and STL winding checks. Both rounds were entirely internal —
simulation math, code correctness, test coverage. Round 3 turns
outward: is this technology honestly worth building, where would it
actually go, what would it do to its surroundings, and what's the
single biggest real-world failure mode (fouling) this repo has not yet
engaged with at all.

## Audit: what was missing going into round 3

- **No economics.** Nothing in this repo computed a $/kWh number or
  compared CHORUS-SGH-1 against any real energy-cost benchmark. The
  existing `docs/math/REAL_WORLD_DATA.md` had LCOE *anchors* (a
  literature range) but no working cost model tying them to this
  repo's own BOM and simulation.
- **No siting.** "Co-locate at a desalination plant" was asserted in
  passing in various docs but never grounded in a real plant's real
  flow/salinity numbers.
- **No environmental framing.** A system that touches brine discharge
  chemistry has an environmental story whether or not this repo writes
  it down; leaving it unwritten is itself a choice, and not a good one
  for anything meant to be taken seriously by a site owner or
  regulator.
- **No fouling protocol.** The single most consequential real-world PRO
  failure (Statkraft Tofte, `docs/CANDIDATE_SITES.md` site 3) partly
  came down to fouling, and this repo's entire T0-T2 test protocol
  (`docs/SGH1_TEST_PROTOCOL.md`) only ever specifies clean-water bench
  runs. `data/bench/*.csv` contains zero fouling-relevant data and
  `scripts/calibrate_constants.py` (rounds 1-2) had no way to detect a
  permeability decline over time even if such data existed.

## Round 3 scope (all landed in this PR)

### R3.1 — Real LCOE model
`scripts/lcoe_model.py`: computes $/kWh from the bench BOM's own cost
estimate line (`EST-001`), membrane $/m² anchors, a standard capital
recovery factor, and the existing PRO/parasitics physics simulation —
not a bare literature quote. Full optimistic/conservative x lab/
practical/Statkraft-floor sensitivity sweep.

### R3.2 — Honest economics writeup
`docs/ECONOMICS.md`: states plainly, with real numbers, that
CHORUS-SGH-1 is not cost-competitive with solar/wind/storage at any
power density this repo's simulation can substantiate (best case
~$2/kWh vs. Lazard's ~$0.03-0.09/kWh solar/wind range), and reframes
what *is* honestly true: power density is the whole economic lever,
BOP cost dominates at small scale, and this only makes sense as a
niche waste-stream co-location technology.

### R3.3 — Real candidate sites
`docs/CANDIDATE_SITES.md`: 5 site types with real public data (Perth
Seawater Desalination Plant, Carlsbad Desalination Plant, the
Statkraft Tofte pilot itself as the cautionary real-world benchmark,
the general WaterReuse SWRO-brine class, and a municipal-WWTP class
explicitly flagged as an unverified research gap rather than invented).

### R3.4 — Environmental impact framing
`docs/ENVIRONMENTAL_IMPACT.md`: documented ecological concerns with
brine discharge, real regulatory precedent (California's Desalination
Amendment, Perth's environmental referral process), and an explicit,
honest statement that CHORUS-SGH-1's own dilution-reduces-impact
hypothesis is untested.

### R3.5 — Fouling test protocol + code
`docs/FOULING_TEST_PROTOCOL.md` (a T1f phase extending
`docs/SGH1_TEST_PROTOCOL.md`) plus `fit_L_p_time_series()` in
`scripts/calibrate_constants.py`: splits one bench run into
chronological segments, re-fits L_p per segment, and reports percent
permeability decline — the concrete metric the protocol's flux-decline
gate needs, tested against synthetic declining- and stable-flow
fixtures.

## Milestone table (round 3)

| Milestone | Status |
|---|---|
| R3.1 — Real LCOE model | Done — `scripts/lcoe_model.py` |
| R3.2 — Honest economics writeup | Done — `docs/ECONOMICS.md` |
| R3.3 — Real candidate sites | Done — `docs/CANDIDATE_SITES.md` (4 verified, 1 explicitly flagged as unverified) |
| R3.4 — Environmental impact framing | Done — `docs/ENVIRONMENTAL_IMPACT.md` |
| R3.5 — Fouling test protocol + code | Done — `docs/FOULING_TEST_PROTOCOL.md`, `fit_L_p_time_series()` |
| R3.6 — Real fouling/economic/environmental validation at an actual site | Blocked — requires physical bench access and a real site relationship, same hard-limit class as rounds 1-2's M6/M7b/M8 |

R3.6 is the honest carry-forward: every document and script above is
real analysis grounded in public data and this repo's own simulation,
but none of it has been validated against an actual CHORUS-SGH-1 unit
at an actual site. That is not a gap this round could have closed —
it requires the same physical hardware/site access every prior round's
hard limits have already named.

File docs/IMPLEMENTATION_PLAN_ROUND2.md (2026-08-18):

# Implementation Plan — Round 2

Ordered, commit-sized steps for `feat/roadmap-round-2` (branched from
`feat/roadmap-implementation`, PR #1).

1. **docs: add round-2 roadmap and implementation plan** (this commit).
2. **feat(simulation): vision-stack signal processing
   (`simulation/vision_signal.py`)** — windowed RMS/envelope amplitude
   estimate, circular-statistics phase-coherence over a rolling window
   of `$SGHV` samples, and an `eta_tink` coupling-efficiency estimate
   bridging to `simulation.differential_tink`.
3. **test(simulation): vision_signal correctness tests** — synthetic
   sine-wave sample streams with known amplitude/phase; assert RMS and
   coherence estimates match analytically expected values within
   tolerance; assert a phase-incoherent stream yields low coherence.
4. **feat(daq): harden dashboard.py against concurrent/partial reads** —
   any bug fixes surfaced by the new tests in step 5 (e.g. read races,
   malformed-field handling) land here.
5. **test(daq): dashboard race/edge-case tests** — mid-append CSV read,
   concurrent GETs, window boundary cases, malformed numeric fields.
6. **feat(scripts): multi-run aggregate calibration with confidence
   intervals** — `fit_L_p_aggregate()` in `calibrate_constants.py` using
   `scipy.stats.t` for a 95% CI and an outlier flag.
7. **test(scripts): aggregate calibration tests** — synthetic multi-run
   fixture with a known outlier; assert the CI and outlier flag are
   correct.
8. **feat(scripts): protocol-history CLI (`scripts/protocol_history.py`)**
   — scans `data/bench/*/checkpoint.json` + `manifest.json` +
   `bench_validation.json`, renders a table, supports `--json` and
   `--test-id`.
9. **test(scripts): protocol_history tests** — synthetic checkpoint/
   manifest/validation fixtures in a tmp dir; assert table contents and
   JSON output shape.
10. **feat(scripts): STL winding-consistency + ASCII-STL rejection in
    `stl_check.py`** — directed-edge counting to detect inconsistent
    winding; explicit `solid` header sniff for ASCII STL rejection.
11. **test(scripts): STL winding/ASCII-rejection tests** — a
    consistently-wound closed mesh, a deliberately flipped-winding
    triangle, and an ASCII STL fixture.
12. **docs: update docs/ROADMAP_ROUND2.md status + README round-2
    section** reflecting what actually landed.

Constraints carried over from round 1: keep all pre-existing tests
green throughout; label all data provenance explicitly; document any
genuine hardware/toolchain blocker instead of skipping silently.

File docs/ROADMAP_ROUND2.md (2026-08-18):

# Round 2 Roadmap — Post-PR#1 Audit

This picks up where `docs/ROADMAP.md` (round 1, see PR #1 /
`feat/roadmap-implementation`) left off. Round 1 shipped real protocol
plumbing, calibration, geometry-check code, checkpointing, a dashboard,
and vision-stack framing. This round audits what round 1 actually left
thin and does the next honest layer of work — not busywork, not
re-wrapping the same functions.

## Audit of round 1's gaps

- **`$SGHV` is protocol-only.** `daq/protocol.py` and
  `daq/serial_sensors.py` can frame, checksum, and multiplex vision-stack
  telemetry, but nothing downstream *interprets* `us_amplitude_mV`,
  `us_phase_deg`, `piezo_array_V` as a signal. There is no envelope
  detection, no phase-coherence estimate across samples, no coupling
  with the UDT/AOR/VOH math already in `simulation/differential_tink.py`
  / `simulation/vortex_osmotic_hydro.py`. This is the single biggest gap
  — round 1 explicitly called it "protocol-complete", not
  "signal-processing-complete".
- **`daq/dashboard.py` has only 3 tests**, all against a static fixture
  CSV. There is no test that the server handles a CSV actively being
  appended to mid-request (the real operating condition), no test of
  concurrent requests, and no coverage of the `window` truncation
  boundary or of a CSV with malformed/missing columns.
- **`scripts/calibrate_constants.py` fits from a single CSV (or a set of
  CSVs treated as one pooled sample) with no per-run breakdown,
  no confidence interval, and no way to see whether L_p is consistent
  run-to-run** (an operator running T1 three times has no way to know if
  the fits agree or one run was an outlier).
- **`checkpoint.json` is a private implementation detail of
  `run_test_protocol.py`.** There is no CLI to inspect run history across
  multiple `data/bench/<TEST>_<date>/` directories, so answering "which
  bench sessions have I actually completed, and what's their pass/fail
  status" means manually grepping JSON files.
- **`scripts/stl_check.py`'s watertightness check has known blind spots**:
  it does not detect self-intersecting (non-manifold-but-technically-
  edge-paired) geometry, does not check triangle winding
  consistency (a mesh can be edge-paired-closed yet have inconsistent
  normals — not truly manifold), and silently accepts ASCII-format STL
  as "too small" garbage rather than giving a clear "wrong format"
  error.

## Round 2 scope

### R2.1 — Vision-stack signal processing (real math, this PR)
Add `simulation/vision_signal.py`: turns a stream of `$SGHV` samples
into the quantities the UDT/AOR/VOH math actually consumes —
envelope/RMS amplitude estimation, phase-coherence (circular variance)
across a rolling window, and a coupling-efficiency estimate feeding
`simulation.differential_tink.sweep_eta_tink`. This is real signal
processing (windowed RMS, circular statistics for phase), not another
protocol pass-through, and is unit-tested against synthetic sine-wave
sample streams with known amplitude/phase so the math is verifiably
correct.

### R2.2 — Dashboard hardening (this PR)
Add tests for: CSV mutated mid-request (append-while-reading race),
concurrent GETs against the running server, `window` boundary behavior
(window larger than file, window=0), and a CSV with missing/malformed
numeric fields (falls back to the raw string rather than crashing).
Fix any bugs these surface.

### R2.3 — Multi-run aggregate calibration with confidence intervals (this PR)
Extend `scripts/calibrate_constants.py` with `fit_L_p_aggregate()`:
runs the existing per-CSV fit across N runs, reports mean, sample
standard deviation, and a t-distribution-based 95% confidence interval
(using `scipy.stats`, already a dependency) — and flags any run whose
fit is more than 2 standard deviations from the pooled mean as a
candidate outlier for operator review.

### R2.4 — Protocol-history CLI (this PR)
`scripts/protocol_history.py`: scans `data/bench/*/checkpoint.json` +
`manifest.json`, and prints a table of test id, completed steps,
pass/fail (from `bench_validation.json` if present), and timestamp.
Supports `--json` for machine-readable output and `--test-id` filtering.

### R2.5 — STL checker hardening (this PR)
Extend `scripts/stl_check.py`: detect inconsistent triangle winding
(an edge shared by two triangles traversed in the *same* direction
indicates inconsistent winding / a non-orientable patch, distinct from
an open edge), and detect and clearly reject ASCII-format STL input
(`solid ...` text header) with a specific error message instead of a
generic "too small" one.

## Milestone table (round 2)

| Milestone | Status |
|---|---|
| R2.1 — Vision-stack signal processing | Done — `simulation/vision_signal.py` |
| R2.2 — Dashboard race/edge-case hardening | Done — fixed a real `window=0` bug, added race/malformed-field tests |
| R2.3 — Multi-run calibration + confidence intervals | Done — `fit_L_p_aggregate()`, MAD-based outlier flagging |
| R2.4 — Protocol-history CLI | Done — `scripts/protocol_history.py` |
| R2.5 — STL winding-consistency + ASCII-STL rejection | Done — `scripts/stl_check.py` |
| R2.6 — Real vision-stack hardware validation of R2.1's algorithms | Blocked — no physical transducer/piezo attached (same hard limit as round 1's M7b) |

Same hard limits as round 1 apply and are not re-litigated here: no
physical DAQ, bench, or CHORUS-SGH-1 skid is attached in this
environment. Everything in R2.1-R2.5 is real, tested code; R2.6 is the
only round-2 item that hardware access would unblock.

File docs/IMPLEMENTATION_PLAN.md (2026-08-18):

# Implementation Plan — Roadmap Execution

Ordered, commit-sized steps for `feat/roadmap-implementation`. Each step
is meant to land as one working, tested commit.

1. **docs: add roadmap and implementation plan** (this commit) — no code.
2. **feat(daq): add framed ASCII serial protocol encoder/parser
   (`daq/protocol.py`)** — pure parsing/checksum logic, unit tested with
   synthetic byte streams (good frames, corrupted checksum, truncated
   frame, frame split across two reads, garbage prefix before a valid
   frame).
3. **feat(daq): real pyserial ingestion in `daq/serial_sensors.py`** —
   opens the configured `--port` for real, with connect timeout,
   per-read timeout, reconnect-with-backoff, checksum-validated frame
   decode via `daq/protocol.py`, and an explicit repeated
   `RuntimeWarning` + stderr message whenever it falls back to
   simulated data (missing port, open failure, or no valid frames within
   timeout). Never silently substitutes simulation.
4. **test(daq): serial protocol + fallback-path tests** — feed a fake
   `serial.Serial`-like object (in-memory) through `read_sensors_serial`
   to prove: good-frame decode, checksum-fail rejection + fallback
   warning, port-open-failure + fallback warning, reconnect-after-drop.
5. **feat(simulation): constant-calibration script
   (`scripts/calibrate_constants.py`)** — OLS fit of membrane
   permeability `L_p` from `P_feed - P_draw` vs. `Q_draw`, and RPM->torque
   slope from `omega_rpm` vs. `P_spin_motor_W / omega_rad_s`. Runs
   against the existing simulated CSVs in `data/bench/`, writes a JSON
   report clearly labeled `"data_provenance": "simulated"`.
6. **test(simulation): calibration fit tests** — synthetic CSV with a
   known-slope relationship, assert the fit recovers it within
   tolerance; assert the report is labeled simulated.
7. **feat(scripts): geometry manifold check in `audit_openscad.py`** —
   shell out to `openscad` CLI per part when available; otherwise record
   `"geometry_check": "skipped: openscad not found"` per part. Add a
   pure-python STL sanity checker (triangle count, degenerate-triangle
   detection) usable when an STL is produced.
8. **test(scripts): audit_openscad geometry-check gap/behavior test** —
   verify the audit records the explicit skip reason when `openscad` is
   absent, and (if present) that a hand-built valid/invalid STL is
   classified correctly by the pure-python checker.
9. **feat(scripts): checkpointing + `--resume` in
   `run_test_protocol.py`** — write `checkpoint.json` after each
   completed sub-run; `--resume` skips already-completed entries.
10. **test(scripts): checkpoint resume logic** — simulate a partial
    checkpoint file and assert the resume path only re-runs the missing
    phases (mock the subprocess calls).
11. **feat(daq): lightweight live dashboard (`daq/dashboard.py`)** —
    stdlib `http.server`-based JSON+HTML polling viewer over the active
    bench CSV; no new dependency.
12. **test(daq): dashboard data-endpoint test** — start the server on an
    ephemeral port against a fixture CSV, hit the JSON endpoint, assert
    shape.
13. **docs: update README with new scripts/usage + roadmap link** and
    final `docs/ROADMAP.md` status-table refresh reflecting what
    actually landed vs. deferred.

Constraints carried through every step: keep all 11 pre-existing tests
green; never claim real hardware was exercised; label all bench data
provenance explicitly (`simulated` vs. `real`) in any script output.

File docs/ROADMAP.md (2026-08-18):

# CHORUS-SGH-1 Harness Roadmap

## Current state (honest baseline, 2026-08-17)

This repo is a physics-simulation + open-hardware R&D harness. The math
(PRO cycle, parasitics, pi_groups, acoustic/vortex vision stack) is real
and covered by tests (11/11 passing at time of writing). Nothing here has
been validated against physical hardware yet:

- `daq/serial_sensors.py` never actually opens a serial port. It accepts
  `--port` but silently discards it and always returns simulated rows
  from `daq.logger.read_sensors_sim`, tagged only with `serial_port` for
  cosmetic traceability. There is no protocol, no framing, no checksum,
  no timeout/reconnect handling — it is a passthrough stub, not a driver.
- `simulation/constants.py` hard-codes `L_p`-class membrane constants and
  a `tau_spin_from_rpm` linear torque model from literature anchors
  (`docs/math/REAL_WORLD_DATA.md`), explicitly marked "calibrate T1c" —
  i.e. placeholders pending real bench data.
- `hardware/openscad/*.scad` (23 parts) are audited today only for
  textual structure (modules, includes, parameter dumps) in
  `scripts/audit_openscad.py`. There is no manifold/watertightness or
  dimensional-tolerance check — geometry could be self-intersecting or
  non-printable and the audit would not catch it.
- `scripts/run_test_protocol.py` runs T0 -> T1 -> T1b -> T1c end to end
  with no checkpointing. If phase 3 of 4 fails (bench disconnect, bad
  fixture, power loss), the whole protocol must restart from T0.
- `daq/logger.py` writes CSV only. There is no live view of a running
  bench session; you can only inspect after the run completes.
- The BOM (`hardware/bom/SGH1_BOM.csv`) specifies `DAQ-001: Raspberry Pi
  4 + ADC HAT (Adafruit/MCP3008)` plus `SENS-001..003` pressure/
  conductivity/flow sensors and `AEH-003` an ultrasonic transducer. The
  realistic bench topology is: an MCU (or the Pi itself acting as a
  serial-attached sensor node) samples the MCP3008 over SPI locally and
  streams framed ASCII telemetry over a USB-CDC serial link to whatever
  machine runs this harness. That is the protocol this roadmap targets.

## Roadmap

### 1. Real DAQ serial ingestion protocol (this PR)
Implement a genuine, protocol-correct ASCII/checksummed serial link in
`daq/serial_sensors.py`, backed by a testable parser in `daq/protocol.py`:
- NMEA-style framed sentences: `$SGH1,<seq>,<millis>,<11 sensor fields>*<XOR checksum hex>\r\n`
- Real `pyserial` port open with configurable baud, connect timeout, and
  per-read timeout.
- Reconnect-with-backoff on port loss (device unplugged mid-run).
- Checksum validation; malformed/short/garbled frames are dropped and
  counted, not silently accepted.
- Explicit, loud fallback: only if the port cannot be opened, or no
  valid frame arrives within the configured timeout, do we fall back to
  `read_sensors_sim`, and we print/log a `RuntimeWarning`-level message
  every time a fallback happens (not once, not silently).
- Unit-testable without hardware: feed synthetic byte streams (good
  frames, corrupted frames, partial frames split across reads) into the
  parser.

### 2. Constant-calibration pipeline (this PR)
`scripts/calibrate_constants.py`: fits membrane permeability `L_p`
(from feed/draw pressure differential vs. flow) and the RPM->torque
coefficient (from `omega_rpm` vs. `P_spin_motor_W`) from bench CSVs
using ordinary least squares (`numpy.polyfit` / `scipy.optimize`).
Validated in this PR against the *simulated* CSVs already in
`data/bench/` (`T1_baseline_*.csv`, `smoke_test.csv`) as a stand-in —
those are clearly synthetic/simulated data, not real bench
measurements. Real T1 calibration still requires physical bench access;
this pipeline is what will consume that data once it exists.

### 3. CAD/STL geometry validation (this PR, partial)
Extend `scripts/audit_openscad.py` with a manifold/watertightness check
per part: shell out to the `openscad` CLI (`--export-format=binstl`) to
render each part to STL, then check basic mesh sanity (triangle count >
0, no degenerate triangles, closed-ness via a numpy-stl / manual
edge-pairing check if `numpy-stl` isn't available). If the `openscad`
binary is not present on the machine (it is not, in this dev
environment — confirmed via `which openscad`), the audit records that
gap explicitly per-part (`"geometry_check": "skipped: openscad not found"`)
rather than pretending to pass.

### 4. Resumable T0->T1->T2 protocol runner (this PR)
`scripts/run_test_protocol.py` gains a checkpoint file
(`<out_dir>/checkpoint.json`) recording which phases/sub-runs completed.
`--resume` re-enters at the first incomplete phase instead of
restarting. A crash or hardware disconnect mid-protocol no longer loses
completed phases.

### 5. Live dashboard mode (this PR, lightweight)
A small stdlib-only local HTTP server (`daq/dashboard.py`) that tails
the active bench CSV and serves a polling HTML page with the latest
readings and a rolling sparkline. No new heavy dependency (Flask is not
in `pyproject.toml`; a `http.server`-based JSON+HTML endpoint keeps the
dependency footprint at zero).

### 6. Vision-stack sensor hookup (this PR, protocol-complete)
`docs/UDT_PHYSICS.md` / `docs/VOH_PHYSICS.md` describe the acoustic
vortex-vision math (AOR/UDT/VOH). `AEH-003` (28kHz ultrasonic
transducer) and the PVDF piezo array (`AEH-002`) are wired into the
same serial link as a second sentence type, `$SGHV,...`, multiplexed
alongside the existing `$SGH1` process-sensor sentence
(`daq/protocol.py`, `daq/serial_sensors.py::read_vision_sensors_serial`).
The framing, checksum, multiplexed reassembly, real-hardware-first
read path, and loud simulated fallback are all fully implemented and
unit tested with synthetic byte streams. What remains a genuine
hardware gap: there is no physical ultrasonic transducer or piezo array
attached in this environment, so the fallback path for `$SGHV` uses a
clearly-labeled simulated placeholder, and the vision stack's
`eta_tink` coupling coefficient still needs fitting against real spin
data once T1c bench torque calibration exists.

### 7. Milestone tracking
| Milestone | Status |
|---|---|
| M0 — Simulation math validated (11/11 tests) | Done (pre-existing) |
| M1 — Real serial protocol + explicit fallback | Done — `daq/protocol.py`, `daq/serial_sensors.py` |
| M2 — Constant-calibration pipeline (sim-data validated) | Done — `scripts/calibrate_constants.py` |
| M3 — Geometry manifold checks in CAD audit | Code done; gate itself blocked — no `openscad` binary in this environment (see below) |
| M4 — Resumable protocol runner | Done — `scripts/run_test_protocol.py` checkpoint/`--resume` |
| M5 — Live dashboard | Done — `daq/dashboard.py` |
| M6 — Real T1/T1c bench data collected, constants refit from hardware | Blocked — requires physical bench access (hard limit) |
| M7 — Vision-stack sensor hookup (AEH-003, AEH-002) protocol + ingestion | Done — `$SGHV` sentence, multiplexed reads, tested |
| M7b — Vision-stack real transducer/piezo data + `eta_tink` fit | Blocked — no physical transducer/piezo attached (hard limit); depends on M6 |
| M8 — Full T0->T2 hardware-in-the-loop run | Blocked — requires a physical CHORUS-SGH-1 skid (hard limit) |

Every item above that is not explicitly "Blocked" is fully implemented
and covered by tests in this PR, not scaffolded or partially done. The
three "Blocked" rows share one root cause: no physical DAQ, bench, or
CHORUS-SGH-1 unit is attached in this environment. M3 is a special
case — the *code* (openscad CLI invocation + pure-python STL
manifold/watertightness checker) is complete and tested against
synthetic STL fixtures; only the actual per-part gate is blocked
because the `openscad` binary itself is not installed here (confirmed
via `which openscad`). Installing it would let the existing code run
immediately with no further changes.

Hardware-in-the-loop validation (M6-M8) cannot be completed in this
environment: there is no physical DAQ, no bench, no CHORUS-SGH-1 unit
attached. Everything above that claims "real" is real *code* — a
correct, testable implementation of the ingestion/calibration/audit
logic — not a claim that it has been run against a physical skid.

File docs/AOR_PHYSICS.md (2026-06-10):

# Acoustic-Osmotic Ram (AOR)

**AOR** stacks natural amplifiers: **resonant sound** strips the membrane, **brine osmotic pressure** propels flow, **hyperspeed draw pipe** multiplies hydraulic head.

**Parent:** [VISION.md](VISION.md) · **Coupling:** [UDT_PHYSICS.md](UDT_PHYSICS.md)

---

## 1. Concept

```
  SOUND + WATER (feed / effluent)
           │
           ▼
  ┌────────────────────┐
  │ RESONANT COLUMN    │  Q-factor amplifier
  │ acoustic streaming │  strips CP boundary layer
  └─────────┬──────────┘
            │ membrane
            ▼
  ┌────────────────────┐
  │ BRINE PLENUM       │  Δπ osmotic motor (MPa)
  │ (draw solution)    │
  └─────────┬──────────┘
            │
            ▼
  ┌────────────────────┐
  │ HYPERSPEED PIPE    │  converging draw leg
  │ (ram + Bernoulli)  │  hydraulic amplifier
  └─────────┬──────────┘
            ▼
     turbine / PX → P_work
            │
            ▼
  recirculating brine loop (working fluid)
```

**Tagline:** Sound strips. Brine propels. Pipe amplifies.

---

## 2. Resonant feed column

### 2.1 Acoustic intensity

$$I = \frac{p_{\mathrm{rms}}^2}{\rho c}$$

See `simulation/acoustic_harvest.py` (AEH Mode A harvest is supplemental; AOR uses Mode B actuation).

### 2.2 Resonance Q

For water column height `H` and quarter-wave match `f ≈ c/(4H)`:

$$Q \approx \frac{\omega_0}{\Delta\omega}$$

Stored cyclic energy scales as `Q × P_driver`. Local **acoustic streaming** velocity at membrane wall:

$$v_{\mathrm{stream}} \propto \frac{I}{\rho c} \cdot f$$

**Role:** dilutes **concentration polarization** at the wall, not bulk brine salinity.

### 2.3 Attribute stripping

| Stripped layer | Mechanism |
|---|---|
| CP film | Streaming + oscillatory shear |
| Hydration shell | High-frequency boundary oscillation |
| Fouling gel | Controlled micro-shear (avoid uncontrolled cavitation) |

Effective result: `k_m ↑`, `g_UDT ↑` (UDT Tink input).

---

## 3. Brine motor (osmotic)

Draw brine at `c_draw` (e.g. 1400 mol/m³) vs feed at `c_feed` (e.g. 5 mol/m³):

$$\Delta\pi = i R T (c_{\mathrm{draw}} - c_{\mathrm{feed}})$$

SGH-1 default: **Δπ ≈ 6.92 MPa**, **ΔP* ≈ 34.6 bar**.

Water flux (solution-diffusion):

$$\dot V_w = L_p A (\Delta\pi - \Delta P)$$

Brine is the **chemical amplifier** — MPa-scale drive without a dam.

---

## 4. Hyperspeed pipe (ram leg)

### 4.1 Converging nozzle

Draw leg area `A(z)` decreasing in flow direction:

$$\rho v \cdot A = \mathrm{const} \quad \Rightarrow \quad v \uparrow \text{ as } A \downarrow$$

Bernoulli (steady, inviscid reference):

$$P + \tfrac{1}{2}\rho v^2 + \rho g z = \mathrm{const}$$

### 4.2 Water hammer / ram (transient)

Pressure spike on sudden momentum change:

$$\Delta P_{\mathrm{ram}} \approx \rho c_{\mathrm{sound}} \,\Delta v$$

Pressure exchanger (`sgh1_px_module`) recovers a fraction `η_px` of draw pressurization energy.

### 4.3 Output

Pressurized **working brine stream** at design rating; permeate flux coupled to hydraulic work:

$$P_{\mathrm{hyd}} = \rho \dot V_w \Delta P \cdot \eta_{\mathrm{hyd}}$$

---

## 5. Combined AOR power density

Illustrative extractable head:

$$\Delta P_{\mathrm{eff}} \approx \Delta P_{\mathrm{osm}} + \rho g \Delta h_{\mathrm{z}} - \Delta P_{\mathrm{loss}}$$

where `Δh_z` is axial leg height (see [VOH_PHYSICS.md](VOH_PHYSICS.md)).

$$P_{\mathrm{AOR}} \approx \eta_{\mathrm{mem}}\eta_{\mathrm{hyd}}\,\rho\,L_{p,\mathrm{eff}}\,A\,(\Delta\pi - \Delta P)\Delta P - P_{\mathrm{US}} - P_{\mathrm{pump}} + P_{\mathrm{px}}$$

---

## 6. Natural amplifiers summary

| Stage | Amplifier | Input | Output |
|---|---|---|---|
| Resonant column | Q | W driver | Local streaming / `k_m` gain |
| Brine plenum | Δπ | Salinity gradient | MPa osmotic head |
| Hyperspeed pipe | Ram / area change | Flux momentum | Pressure recovery |
| PX | η_px | Draw pressure | Feed pressurization credit |

**Not claimed:** acoustic areal power comparable to solar (~1 kW/m²). AOR taps **osmotic + hydraulic** head; sound is the **unlock**, not the primary reservoir.

---

## 7. Code

```bash
python -c "from simulation.acoustic_osmotic_ram import aor_state; print(aor_state())"
```

Module: `simulation/acoustic_osmotic_ram.py`

Experiment: **E15** → `vision_stack.aor`

---

## 8. Hardware mapping

| AOR stage | SGH-1 part |
|---|---|
| Resonant column | `chorus_skid_enclosure`, feed manifold |
| Membrane | `sgh1_membrane_*` stack |
| Brine plenum | draw manifold, brine tank adapter |
| Hyperspeed pipe | `sgh1_manifold_draw` → `sgh1_px_module` → `sgh1_turbine_housing` |
| UDT | `chorus_aeh_panel`, `sgh1_us_mount_ring` |

Planned: `sgh1_z_pipe.scad` (axial leg).

---

## 9. Validation (T1b)

1. Baseline PRO, no US, no resonance tuning.
2. Enable resonant column (match `f_us` to column `H`).
3. Enable UDT phased rays.
4. Compare `P_net` at 30 min and 60 min (fouling window).

Pass: **AOR chain beats baseline at ≥ 60 min** on same brine simulant.

---

*See also: [CHORUS_ACOUSTIC_LAYER.md](CHORUS_ACOUSTIC_LAYER.md), [math/PRO_LAYER_DERIVATION.md](math/PRO_LAYER_DERIVATION.md)*

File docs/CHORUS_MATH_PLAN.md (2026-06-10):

# CHORUS — Mathematical & Physical Proof Plan

**CHORUS** = *Columnar Harvest of Osmotic, Rhizospheric, Orographic, and Solar flux*

This document is the derivation blueprint. The executable proof lives in **`notebooks/CHORUS_physics_proof.ipynb`**.

---

## 0. Axioms & notation

| Symbol | Meaning | SI |
|---|---|-----|
| $R$ | Gas constant | J/(mol·K) |
| $F$ | Faraday constant | C/mol |
| $T$ | Temperature | K |
| $z$ | Ion valence | 1 |
| $c_i$ | Molar concentration | mol/m³ |
| $\psi$ | Electric potential | V |
| $\pi$ | Osmotic pressure | Pa |
| $\mathbf{N}$ | Molar flux | mol/(m²·s) |
| $\mathbf{J}_q$ | Energy flux | W/m² |

**Postulate (no over-unity):** Total electrical power extracted from the column at steady state satisfies
$$\sum_k P_k \leq \sum_j \dot{E}_{j,\mathrm{in}} - \dot{S}T$$
where $\dot{E}_{j,\mathrm{in}}$ are exogenous fluxes (solar irradiance, geochemical mixing, wind kinetic, etc.) and $\dot{S}T$ is dissipation.

---

## 1. Layer A — Osmotic mixing & blue energy (RED)

### 1.1 Gibbs free energy of ideal electrolyte mixing

For species $i$ transferring from reservoir $+$ to $-$:
$$\Delta g_{\mathrm{mix}} = RT \sum_i \int \ln\frac{a_i^+}{a_i^-}\,dc_i$$

For single 1:1 salt NaCl with $c^+ = c^-$ (activity $a \approx c$):
$$\Delta G_{\mathrm{mix}} = 2RT\,V\,\left(c_+\ln\frac{c_+}{c_-} - (c_+-c_-)\right)$$

### 1.2 Van't Hoff osmotic pressure
$$\pi = i\,RT\,c \quad (i=2\ \text{for NaCl})$$
$$\Delta\pi = \pi_{\mathrm{sea}} - \pi_{\mathrm{river}}$$

### 1.3 Hydraulic / mixing power ceiling
$$\boxed{P_{\mathrm{mix,max}} = \Delta\pi \cdot Q}$$
with $Q$ = volumetric flow of fresh water into the mixing zone (m³/s).

### 1.4 Nernst membrane potential (single pair)
$$\boxed{E_N = \frac{RT}{zF}\ln\frac{a_{\mathrm{high}}}{a_{\mathrm{low}}}}$$
Stack of $n$ pairs: $V_{\mathrm{oc}} = n E_N$.

### 1.5 Electrical max-power theorem (linear internal resistance)
$$P_{\mathrm{elec}} = IV,\quad V = V_{\mathrm{oc}} - R_{\mathrm{int}} I$$
$$\boxed{P_{\mathrm{max}} = \frac{V_{\mathrm{oc}}^2}{4R_{\mathrm{int}}}} \quad\text{(per unit area if }R_{\mathrm{int}}\text{ is Ω·m²)}$$

### 1.6 Nanopore conductance (slip-corrected, 2026 scaling)
Hagen–Poiseuille + surface charge → conductance $G$ [S/m²]. Hydration lubrication enters as effective slip length $b$:
$$G(b) = G_0\left(1 + \frac{2b}{h}\right)$$
$$P_{\mathrm{np}} = \tfrac{1}{4} G(b)\,V_{\mathrm{oc}}^2$$

**Calibration anchor:** $P_{\mathrm{np}} \approx 15\ \mathrm{W/m^2}$ at $c_{\mathrm{sea}}\approx600$, $c_{\mathrm{river}}\approx20$ mol/m³ (Nature Energy 2026).

---

## 2. Layer B — Moist-electric & hydrovoltaic (orographic)

### 2.1 Water vapor chemical potential
$$\mu_v = \mu_v^\circ(T) + RT\ln a_w,\quad a_w \approx \mathrm{RH}$$
Flux (Fick): $N_v = -D_{\mathrm{eff}}\nabla c_v$.

### 2.2 Asymmetric nanopore charge separation (Air-gen class)
Collision rate on surface $\propto$ molecular flux $\Gamma \propto p_v/\sqrt{2\pi m k_BT}$.
Top vs bottom pore opening area asymmetry $\Rightarrow$ net charge current:
$$\boxed{I_q = e\,\Delta\Gamma\,\bar{q}_{\mathrm{trans}}}$$
Open-circuit: $V_{\mathrm{oc}} \approx I_q/G_{\mathrm{pore}}$.

### 2.3 Streaming potential (hydrovoltaic)
Helmholtz–Smoluchowski:
$$\boxed{E_s = \frac{\varepsilon\zeta}{\sigma}\frac{\Delta p}{\eta}}$$
Streaming current $I_s = \sigma_{\mathrm{eff}} E_s$ (thin double layer).

### 2.4 PV–thermal–evaporative node (coupled)
$$C_{\mathrm{th}}\frac{dT_s}{dt} = \alpha_s G_{\mathrm{solar}} - h_c(T_s-T_\infty) - L_v\dot{m}_e - P_{\mathrm{hybrid}}$$
$$\dot{m}_e = h_m\bigl(c_v^*(T_s)-c_v^\infty\bigr)$$
PV efficiency: $\eta_{\mathrm{pv}}(T_s) = \eta_0\bigl[1 - \beta(T_s-T_{\mathrm{ref}})\bigr]$.

**Coupling gain (EES 2026 class):** waste heat feeds MHD → $\Delta P_{\mathrm{MHD}}/\Delta P_{\mathrm{PV}} \sim 1.5$ on MHD side, $\sim0.15$ on PV side.

---

## 3. Layer C — Rhizosphere (SMFC + piezoelectrotrophy)

### 3.1 Butler–Volmer at anode
$$j = j_0\left[\exp\frac{\alpha_a F\eta}{RT} - \exp\frac{-\alpha_c F\eta}{RT}\right],\quad \eta = E - E_{\mathrm{eq}}$$

### 3.2 Fuel-cell power density
$$P = j(E_0 - b\log j - R_\Omega j)$$
Maximize over $j$ → $P_{\mathrm{mp}}$.

### 3.3 Piezoelectric constitutive (d₃₃ mode)
$$D = d_{33}\sigma + \varepsilon^T E,\quad S = s^E\sigma + d_{33}E$$
Energy per cycle: $U = \frac{1}{2}\int \sigma\,S\,\mathrm{d}V$.

### 3.4 Piezoelectrotrophy coupling
Mechanical power density $P_{\mathrm{mech}}$ from root growth / rain / freeze–thaw:
$$\dot{E}_{\mathrm{bio}} = \eta_{\mathrm{pzt}}\,P_{\mathrm{mech}}$$
feeds exoelectrogenic carbon fixation (parallel pathway to substrate oxidation).

---

## 4. Layer D — Atmospheric charge & collision cells

### 4.1 Fair-weather global circuit
Ionosphere–surface capacitor: $I_{\mathrm{glob}} \approx 1\text{–}3\ \mathrm{kA}$, $V \approx 200\text{–}400\ \mathrm{kV}$:
$$\boxed{P_{\mathrm{glob}} = I_{\mathrm{glob}} V \approx 0.25\text{–}0.9\ \mathrm{GW}}$$
Areal mean: $P'' \approx P_{\mathrm{glob}}/4\pi R_\oplus^2 \sim 10^{-4}\ \mathrm{W/m^2}$.

### 4.2 Droplet collision charging (Mason scaling)
$$\frac{\mathrm{d}q}{\mathrm{d}t} \approx \alpha_{\mathrm{coll}}\,n_d^2\,\pi d^2\,v_{\mathrm{rel}}\,\Delta q$$
Power in volume $V$: $P = \frac{\mathrm{d}q}{\mathrm{d}t} V_{\mathrm{coll}}$.

### 4.3 Tornado kinetic sanity (not harvest target)
$K = \frac{1}{2}\rho V_{\mathrm{tor}} \pi (D/2)^2 H$ — episodic GW, not steady baseload.

---

## 5. CHORUS coupling — Telluric Storm Coupling (TSC)

Three-node conductance network (atmosphere $a$, soil $s$, estuary $w$):

$$\mathbf{G}\boldsymbol{\psi} = \mathbf{I}$$
$$\mathbf{G} = \begin{bmatrix}
G_{as}+G_{s0} & -G_{as} & 0 \\
-G_{as} & G_{as}+G_{sw} & -G_{sw} \\
0 & -G_{sw} & G_{sw}+G_{w0}
\end{bmatrix}$$

Dissipated power: $P_{\mathrm{TSC}} = \boldsymbol{\psi}^\top \mathbf{G}\boldsymbol{\psi}$.

**Interpretation:** CHORUS is not a new energy source; TSC routes **already-separated** charge between layers, improving utilization of high-impedance harvesters (MEG, SMFC).

---

## 6. Column balance (1 km² coastal parcel)

$$\boxed{P_{\mathrm{column}} = \sum_k A_k\,\mathrm{CF}_k\,\langle P_k''\rangle}$$

Monte Carlo on $\ln P_k''$ with literature medians and uncertainties.

**Expected hierarchy (honest):**
1. PV–hydro land ($\sim 10^2$ W/m² footprint-weighted)
2. Blue energy estuary ($\sim 10^1$ W/m² on interface)
3. MEG / collision ($\sim 10^{-2}$–$10^0$ W/m²)
4. SMFC ($\sim 10^{-4}$ W/m²)

---

## 9. Layer F — PRO / anthropogenic brine (SGH-1)

Full derivation: **`docs/math/PRO_LAYER_DERIVATION.md`**. Numeric Π-groups: **`docs/math/DIMENSIONLESS_GROUPS_NUMERIC.md`**. Skid balance: **`docs/math/SKID_ENERGY_BALANCE.md`**.

$$\Delta\pi = iRT(c_\mathrm{brine} - c_\mathrm{feed})$$
$$\Delta P^* \approx \Delta\pi/2$$
$$\dot V_w = L_p A(\Delta\pi - \Delta P), \quad P \approx \eta_\mathrm{mem}\eta_\mathrm{hyd}\,\rho \dot V_w\,\Delta P$$
$$\frac{c_w}{c_b} = \exp(J_w/k_m) \quad\text{(CP)}$$

Bench: `python simulation/run_sizing.py` · Π-groups: `python -m simulation.pi_groups`

---

## 10. Vision stack — UDT / AOR / VOH

**Master index:** [VISION.md](VISION.md)

| Layer | Physics | Key equation |
|---|---|---|
| **UDT** | Ray field + particle bytes → Tink kernel | $k_{m,\mathrm{eff}} = k_{m,0}(1 + \eta_{\mathrm{tink}}\bar{w})$ |
| **AOR** | Resonant column + brine motor + ram pipe | $P_{\mathrm{net}} = P_{\mathrm{PRO}}(g) - P_{\mathrm{US}} - P_{\mathrm{pump}} + P_{\mathrm{px}}$ |
| **VOH** | Spin + z-hydro + osmosis | $P = P_0 + \rho g z + \tfrac{1}{2}\rho\omega^2 r^2 + \Pi_{\mathrm{osm}}$ |

Sim: `differential_tink.py`, `acoustic_osmotic_ram.py`, `vortex_osmotic_hydro.py` · Experiments E14–E16.

---

## 7. Notebook section map

| § | Content | Method |
|---|---|---|
| I | Symbolic Gibbs, Nernst, $P_{\max}$ | SymPy |
| II | RED + slip conductance sweep | NumPy |
| III | MEG flux + $V_{\mathrm{oc}}$ | NumPy |
| IV | Thermal ODE + PV boost | SciPy `solve_ivp` |
| V | Butler–Volmer + piezo | NumPy |
| VI | Global circuit + collision cell | NumPy |
| VII | TSC Kirchhoff + Monte Carlo column | NumPy |

---

## References (anchors)

- Teng et al., *Nat. Energy* 2026 — lipid nanopore blue energy (~15 W/m²)
- Yao et al., *Adv. Mater.* — Air-gen moisture charge separation
- Fang et al., *Energy Environ. Sci.* 2026 — PV–MHD coupling
- NSO 2026 — piezoelectrotrophy paradigm
- Virgo et al., *Glob. Chall.* 2020 — lightning / atmospheric circuit budget

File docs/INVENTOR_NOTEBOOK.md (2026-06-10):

# Inventor Notebook Template

**Project:** CHORUS-Skid SGH-1 + AEH-1 + UDT / AOR / VOH  
**Vision:** [VISION.md](VISION.md)
**Inventor:** ___________________  
**Witness (sign/date):** ___________________

## Entry format

| Date | Description | Signature |
|---|---|---|
| YYYY-MM-DD | Concept: ... | |

## Rules

1. Contemporaneous notes — no backdating
2. Witness every 2 weeks if possible
3. Git commits supplement but do not replace signed pages
4. Photo bench builds with date card

## Key milestones to log

- [ ] First simulation `run_sizing.py` output
- [ ] First CAD export STL
- [ ] First pressurized leak test
- [ ] First positive power measurement
- [ ] UDT documented — [UDT_PHYSICS.md](UDT_PHYSICS.md) + `differential_tink.py` run
- [ ] AOR resonant column tuned — f_res vs column height logged
- [ ] T1b: US/UDT on vs off — `P_net` gain CSV
- [ ] T1c: VOH spin vs flat — `P_net` vs ω CSV
- [ ] First field sidestream T2 contact (utility/lab NDA)

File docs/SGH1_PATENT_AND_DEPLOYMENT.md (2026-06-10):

# Patent & Deployment Playbook (SGH-1 / CHORUS)

**Not legal advice.** Consult a patent attorney before filing or public disclosure.

## Checklist before filing

- [ ] Prior art search (PRO + desal brine + AEH + US membrane)
- [ ] Inventor notebook dated entries
- [ ] Bench reduction to practice (CSV + photos)
- [ ] US provisional filed
- [ ] Entity (LLC) owns IP

## Claim focus

1. Integrated skid: PRO + CHOR plenum + AEH panel + shared DAQ bus
2. Anthropogenic brine + low-sal feed pairing on modular manifold
3. ΔP/Δπ feedback using dual conductivity sensors
4. Dual-mode acoustic: harvest + ultrasonic CP assist
5. **UDT:** Universal Differential Tink — geometry-scaled particle bytes on discrete ray field → `k_m,eff` (see [UDT_PHYSICS.md](UDT_PHYSICS.md))
6. **AOR:** Acoustic-Osmotic Ram — resonant feed column + brine osmotic motor + hyperspeed draw leg ([AOR_PHYSICS.md](AOR_PHYSICS.md))
7. **VOH / Z-Hydro:** Rotating halocline cell + axial z-leg pressurized flux harvest ([VOH_PHYSICS.md](VOH_PHYSICS.md))
8. Toroidal membrane loop on differential spine (line + circle geometry)

Prior art search must include: Statkraft PRO, SWRO–PRO hybrids, PRO-MBR, Taylor–Couette membrane shear, phased ultrasound CP literature.

## Outreach

**Package:** 1-pager + `SGH1_Design_Report.pdf` + bench data under NDA.

| Type | Targets |
|---|---|
| Desal | IDE, Veolia, PUB Singapore, SWCC |
| Labs | NREL, LBL, UC Riverside |
| Programs | ARPA-E, SBIR, Cleantech Open |

## Test sites

- T0: home lab
- T1: university flow loop
- T2: desal sidestream (Carlsbad, Tampa, Fukuoka-class, Gulf)
- Loud urban: plant near freeway + AEH tuning

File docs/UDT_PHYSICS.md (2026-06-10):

# Universal Differential Tink (UDT)

Specification for the **differential-harness** control and actuation layer on toroidal membrane loops.

**Parent:** [VISION.md](VISION.md)

---

## 1. Purpose

The UDT raises **sustainable permeate flux** by:

1. Measuring **osmotic differentials** along the feed spine (line).
2. Driving a **discrete ray field** on each membrane loop (circle).
3. Encoding actuation as **geometry-scaled particle bytes**.
4. Applying the **Tink kernel** to produce effective mass-transfer `k_m,eff` and flux gain.

---

## 2. Geometry

### 2.1 Line (spine)

- Index loops `i = 1 … N_loop` along interconnect length `L_line` [m].
- Conductivity sensors at each node give feed/draw salinity proxy `σ_feed,i`, `σ_draw,i`.

$$\Delta\sigma_i = \frac{\partial \sigma}{\partial x}\bigg|_i \approx \frac{\sigma_{\mathrm{draw},i} - \sigma_{\mathrm{feed},i}}{\Delta x_i}$$

$$\Delta\pi_i = i R T \,\Delta c_i \quad (\Delta c_i \propto \Delta\sigma_i)$$

This implements patent claim **ΔP/Δπ feedback from dual conductivity**.

### 2.2 Circle (loop)

Each loop `i` has:

| Symbol | Meaning |
|---|---|
| `A_loop,i` | Active membrane area [m²] |
| `C_i = 2πR_i` | Loop circumference [m] |
| `L_line,i` | Spine segment length to neighbors [m] |

Membrane is a **closed 1-cycle** — flux and actuation integrate around the ring.

---

## 3. Ray field

### 3.1 Discretization

Design-point ray count:

$$N_r = 64534$$

(parameter `N_RAYS_DEFAULT` in `simulation/constants.py`; may be reduced on bench hardware e.g. 16–64 transducers).

Each ray `k` on loop `i`:

| Quantity | Symbol | Unit |
|---|---|---|
| Surface anchor | `s_k` | m² |
| Direction | `û_k` | — |
| Intensity | `I_k` | W/m² |
| Phase | `φ_k` | rad |

Energy density on the loop surface:

$$\mathcal{E}(\mathbf{r}) = \sum_{k=1}^{N_r} I_k\,\delta(\mathbf{r} - \mathbf{r}_k)$$

**Implementation:** vectorized `numpy` arrays `(N_r,)` — the **vectorized runtime**.

### 3.2 Physical role

Rays deliver **actuation power** (ultrasound / electro-acoustic) that modifies the concentration-polarization boundary layer via increased local shear and `k_m`.

---

## 4. e90 wavelength

**E90** = wavelength band carrying **90%** of coupled actuation power in the ray spectrum.

Default carrier: **f_us = 28 kHz** ultrasonic in water:

$$\lambda_{e90} \approx \frac{c_{\mathrm{sound}}}{f_{\mathrm{us}}} \approx \frac{1500}{28000} \approx 0.054\ \mathrm{m}$$

(`C_SOUND_WATER`, `F_US_DEFAULT` in constants.)

The e90 band sets phased ring timing: traveling wave speed around circumference `C_i` at phase velocity tied to `λ_e90`.

---

## 5. Particle byte

A **particle byte** is a quantized actuation packet per ray per control timestep `Δt`.

### 5.1 Byte length (geometry scaling)

$$\boxed{\texttt{byte\_len}_{k} = \frac{A_{\mathrm{loop},i}}{L_{\mathrm{line},i}} \cdot \frac{\lambda_{e90}}{\lambda_0}}$$

- `λ_0` = reference wavelength (1 m normalization in code).
- Loops with **more membrane per unit spine** receive **longer bytes** → higher control gain.

### 5.2 Energy quantum

$$E_k = I_k \cdot a_k \cdot \Delta t \quad [J]$$

where `a_k` is ray footprint area [m²].

Byte integer (runtime state):

$$b_k = \max\left(1,\ \left\lfloor \frac{E_k}{E_0} \cdot \texttt{byte\_len}_k \right\rfloor\right)$$

State vectors: **B** ∈ ℤ^N_r (bytes), **Φ** ∈ ℝ^N_r (phases).

---

## 6. Tink kernel

The **Universal Differential Tink** maps `(I_k, b_k, φ_k, Δσ_i)` → transport coefficients on loop `i`.

### 6.1 Effective mass-transfer coefficient

$$k_{m,\mathrm{eff},i} = k_{m,0}\left(1 + \eta_{\mathrm{tink}} \cdot \frac{\sum_{k \in \mathrm{loop}\,i} b_k\, I_k \cos\phi_k}{\sum_{k \in \mathrm{loop}\,i} b_k}\right)$$

- `k_m,0` = baseline film coefficient [m/s] (default `D/L` scale from `membrane_transport.py`).
- `η_tink` = coupling efficiency ∈ [0, 1] (calibration constant).

### 6.2 Flux gain

Polarization factor from film model:

$$\frac{c_w}{c_b} = \exp(J_w / k_{m,\mathrm{eff}})$$

Effective flux gain vs baseline:

$$g_{\mathrm{UDT}} = \frac{J_w(k_{m,\mathrm{eff}})}{J_w(k_{m,0})}$$

Feeds `simulation/ultrasonic_cp_gain.py` as **spatial** gain, not a single scalar.

### 6.3 Differential pressure trim

$$\Delta P_i = \mathrm{clip}\left(\Delta P^{*}\cdot\frac{\Delta\pi_i}{\overline{\Delta\pi}},\ \Delta P_{\min},\ \Delta P_{\max}\right)$$

Kim–Baker optimum preserved on average: `ΔP* ≈ Δπ/2`.

---

## 7. Power accounting

Loop production (coupled to `pro_cycle.py`):

$$P_{\mathrm{loop},i} = \eta_{\mathrm{mem}}\eta_{\mathrm{hyd}}\,\rho\,L_{p,\mathrm{eff},i}\,A_{\mathrm{loop},i}\,(\Delta\pi_i - \Delta P_i)\,\Delta P_i$$

Actuation cost:

$$P_{\mathrm{UDT}} = \sum_k I_k a_k + P_{\mathrm{driver}}$$

Net (see [math/SKID_ENERGY_BALANCE.md](math/SKID_ENERGY_BALANCE.md)):

$$P_{\mathrm{net}} = \sum_i P_{\mathrm{loop},i} + P_{\mathrm{AEH}} - P_{\mathrm{UDT}} - P_{\mathrm{pump}} - P_{\mathrm{aux}}$$

---

## 8. Code

```bash
python -c "from simulation.differential_tink import demo; demo()"
```

Module: `simulation/differential_tink.py`

Functions: `ray_field()`, `particle_bytes()`, `tink_kernel()`, `loop_transport_state()`

Experiment: **E14** in `simulation/experiments.py` → `vision_stack.udt`

---

## 9. Bench hardware

- Piezo / US transducers on `chorus_aeh_panel`, `sgh1_us_mount_ring`.
- Conductivity probes on feed/draw manifolds.
- DAQ: `daq/logger.py` at ≥ 1 Hz.
- Planned CAD: `sgh1_tink_ring.scad` (toroidal mount pattern).

---

## 10. Falsification tests

| Test | Prediction if UDT is real |
|---|---|
| US off vs on, same ΔP | `P_net(on) > P_net(off)` after 30 min fouling |
| Phased vs random φ_k | Phased traveling wave beats incoherent |
| Large `A_loop/L_line` | Higher `b_k` loops show larger `g_UDT` |

---

## 11. Constants (calibrate on T1)

| Constant | Default | Source |
|---|---|---|
| `N_RAYS_DEFAULT` | 64534 | design mesh |
| `F_US_DEFAULT` | 28000 Hz | AEH driver |
| `ETA_TINK_DEFAULT` | 0.15 | TBD bench |
| `E0_JOULES` | 1e-6 | byte quantum |

---

*See also: [AOR_PHYSICS.md](AOR_PHYSICS.md), [VOH_PHYSICS.md](VOH_PHYSICS.md)*

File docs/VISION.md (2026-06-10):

# CHORUS Vision — differential-harness

**differential-harness** is the open engineering stack for a new class of water-electricity: **osmotic-vortex hydro** at anthropogenic brine outfalls.

This document is the master index. Detailed physics live in linked specs. Executable models live in `simulation/`.

---

## One sentence

> **Sound strips the membrane. Brine propels the loop. Spin and the z-pipe amplify pressure. The Tink differential bus tunes every loop. Fleet deployment at desal outfalls harvests mixing energy gravity hydro cannot reach.**

---

## The problem

- Desalination discharges **hypersaline brine** (~52–70 g/L, often 1.5–2× seawater).
- Treated effluent nearby stays **low salinity** (~5 mol/m³ class).
- Mixing releases **Gibbs free energy** that is normally wasted as entropy.
- Statkraft (2009–2013) proved PRO in principle (~1 W/m²) and **stopped** on fouling and economics.
- Literature now reports **~6.3 W/m²** PRO on commercial RO membranes (Pedersen et al., 2024).

**Gap:** no shipped modular system combines **acoustic CP stripping**, **differential loop control**, **rotating stratified brine geometry**, and **vertical z-leg work extraction** at sidestream scale.

---

## Architecture stack (bottom → top)

| Layer | Name | Role | Doc | Sim |
|---|---|---|-----|-----|
| 0 | **SGH-1 PRO core** | Brine draw + low-sal feed → pressurized permeate | [SGH1_DEVICE_SPEC.md](SGH1_DEVICE_SPEC.md) | `pro_cycle.py` |
| 1 | **UDT** | Universal Differential Tink — ray field + particle bytes → `k_m,eff` | [UDT_PHYSICS.md](UDT_PHYSICS.md) | `differential_tink.py` |
| 2 | **AOR** | Acoustic-Osmotic Ram — resonant sound + brine motor + hyperspeed pipe | [AOR_PHYSICS.md](AOR_PHYSICS.md) | `acoustic_osmotic_ram.py` |
| 3 | **VOH / Z-Hydro** | Vortex-Osmotic Hydro — rotation + halocline + axial z-pressure harvest | [VOH_PHYSICS.md](VOH_PHYSICS.md) | `vortex_osmotic_hydro.py` |
| 4 | **Fleet** | Cartridge modules at every desal outfall | [SGH1_PATENT_AND_DEPLOYMENT.md](SGH1_PATENT_AND_DEPLOYMENT.md) | `real_world_calibration.py` |

Bench path today: **Layer 0 → 1 → 2**. Layer 3 is the scale-up geometry. Layer 4 is deployment.

---

## Natural amplifiers (no over-unity)

All power is bounded by exogenous flux minus dissipation (see [CHORUS_MATH_PLAN.md](CHORUS_MATH_PLAN.md) §0).

| Amplifier | Mechanism | Typical scale |
|---|---|---|
| **Resonance (Q)** | Acoustic energy stored in water column | Local streaming ↑ |
| **Osmotic Δπ** | Chemical potential brine vs feed | **MPa** class |
| **Hydraulic ram** | Momentum in converging draw leg | Pressure spike / PX recovery |
| **Centrifugal** | `½ρω²r²` in rotating cell | Added draw head + CP shear |
| **Stratification** | `ρ_brine > ρ_fresh` | Halocline engine, z-upwelling |
| **Fleet** | N plants × brine flow | **GWh–TWh** mixing resource |

Sound alone is **mW–W/m²**. Brine mixing at coastal scale is **GWh/year per large plant**.

---

## Geometry (line + circle + z)

```
        feed spine (LINE) ───●────●────●────
                            │    │    │
                         LOOP  LOOP  LOOP   ← membrane circles (UDT)
                            │    │    │
                            └── z-PIPE (axial draw) ──→ work extraction
```

- **Line** = interconnect length `L_line` [m] between loops (hydraulic + sensor bus).
- **Circle** = toroidal membrane loop, area `A_loop`, circumference `C`.
- **z-pipe** = hyperspeed axial draw leg; harvests **vertical pressurized flux** `∂P/∂z`.

---

## Validation ladder

| Stage | Test | Pass criterion |
|---|---|---|
| **T0** | Coupon / single plate | No leaks @ 3 bar; 15 min steady signal |
| **T1** | Full stack | 1 h run; `P_net > 0`; ±30% vs sim |
| **T1b** | UDT / US on vs off | `P_net(US on) > P_net(US off)` same ΔP |
| **T1c** | Spin vs flat | `P_net(ω>0) > P_net(ω=0)` same ΔP |
| **T2** | Field sidestream | Utility NDA; 24 h brine + effluent CSV |
| **T3** | Fleet pilot | SEC reduction or net export $/m³ brine |

Protocol: [SGH1_TEST_PROTOCOL.md](SGH1_TEST_PROTOCOL.md)

---

## Simulation reproduce

```bash
pip install -e .
python -m simulation.experiments    # includes vision_stack (E14–E16)
python -m simulation.run_sizing --power 50
```

Vision exports: `exports/paper_experiments.json` → `vision_stack` key.

---

## Document map

### Vision & physics (this program)

| Document | Content |
|---|---|
| [VISION.md](VISION.md) | This file — master index |
| [UDT_PHYSICS.md](UDT_PHYSICS.md) | Rays, e90, particle bytes, Tink kernel |
| [AOR_PHYSICS.md](AOR_PHYSICS.md) | Acoustic-Osmotic Ram |
| [VOH_PHYSICS.md](VOH_PHYSICS.md) | Vortex-Osmotic Hydro / Z-Hydro |
| [CHORUS_MATH_PLAN.md](CHORUS_MATH_PLAN.md) | Layers A–F, column balance |
| [CHORUS_ACOUSTIC_LAYER.md](CHORUS_ACOUSTIC_LAYER.md) | AEH Mode A/B |

### Math & data

| Document | Content |
|---|---|
| [math/PRO_LAYER_DERIVATION.md](math/PRO_LAYER_DERIVATION.md) | PRO transport |
| [math/SKID_ENERGY_BALANCE.md](math/SKID_ENERGY_BALANCE.md) | `P_net` definition |
| [math/REAL_WORLD_DATA.md](math/REAL_WORLD_DATA.md) | Statkraft, Perth, Pedersen |
| [math/EXPERIMENTAL_RESULTS.md](math/EXPERIMENTAL_RESULTS.md) | E1–E13 + vision E14–E16 |

### Hardware & deployment

| Document | Content |
|---|---|
| [../hardware/BUILD_BLUEPRINT.md](../hardware/BUILD_BLUEPRINT.md) | Build order |
| [SGH1_DEVICE_SPEC.md](SGH1_DEVICE_SPEC.md) | FR-1–FR-5 |
| [SGH1_PATENT_AND_DEPLOYMENT.md](SGH1_PATENT_AND_DEPLOYMENT.md) | Claims, outreach |
| [INVENTOR_NOTEBOOK.md](INVENTOR_NOTEBOOK.md) | Milestones |

---

## Honest claims (tiered)

**Tier 1 — defensible near-term (bench):**
- PRO on anthropogenic brine + effluent
- AEH harvest (supplemental mW)
- Ultrasonic CP assist (net gain if `g ≳ 1.5`)
- UDT differential conductivity → ΔP trim

**Tier 2 — engineering target (T1c/T2):**
- AOR resonant column + ram pipe
- Rotating loop fouling advantage
- Z-leg work extraction

**Tier 3 — civilization scale (fleet):**
- Material SEC reduction at co-located desal + WWTP
- Global brine outfall energy recovery

**Not claimed:** over-unity; sun-equivalent W/m² from acoustics alone; replacement of river hydro.

---

## CAD roadmap (not yet built)

| Part | Purpose | Status |
|---|---|---|
| `sgh1_*` (23 parts) | SGH-1 bench PRO | ✓ OpenSCAD |
| `sgh1_tink_ring.scad` | Toroidal UDT ray mounts | planned |
| `sgh1_z_pipe.scad` | Axial hyperspeed draw leg | planned |
| `sgh1_vortex_basin.scad` | Taylor–Couette / halocline cell | planned |

---

## Pitch (external)

**Category:** Osmotic-vortex hydro (VOH) — water-electricity without a dam.

**Wedge:** Membrane fouling/CP solved by UDT + AOR; brine is the motor; rotation + z-pipe are amplifiers.

**Ask:** Sidestream tap for T2; membrane vendor partnership for L_p validation.

---

*CHORUS Research · differential-harness · June 2026*

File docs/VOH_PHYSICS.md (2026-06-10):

# Vortex-Osmotic Hydro (VOH) / Z-Hydro

**VOH** extends AOR with **rotation** and **vertical (z) pressurized flux** — a new site class for water-electricity: **coastal brine outfalls without river head**.

**Parent:** [VISION.md](VISION.md) · **Builds on:** [AOR_PHYSICS.md](AOR_PHYSICS.md)

---

## 1. Why VOH changes the map

| Classic hydro | VOH / Z-Hydro |
|---|---|
| Requires `ρgΔh` (dam, river) | Requires `Δπ` + optional small `Δh` |
| Dry coasts excluded | **Desal outfalls** worldwide |
| Seasonal flow | **24/7** brine discharge |
| Single physics channel | `ρgΔh + Δπ + ½ρω²r²` stacked |

**Category name:** *osmotic-vortex hydro* — water-electricity from **spinning brine–fresh interfaces**.

---

## 2. Geometry: world vortex cell

Toroidal or cylindrical basin with:

- **Fresh / feed** (light) above or inside.
- **Brine draw** (dense) below or at rim.
- **Halocline** = working membrane interface.
- **Rotation** angular velocity `ω` [rad/s].
- **z-pipe** = axial draw leg extracting **vertical pressurized flux**.

```
        ╭──────── fresh (ρ_f) ────────╮
        │      ↑ z-upwelling core      │
        │  ═══ halocline / membrane ══ │  ← ω (spin)
        │      brine (ρ_b) → rim       │
        ╰────────────┬────────────────╯
                     │ z-PIPE
                     ▼
              work extraction (PX / turbine)
```

---

## 3. Pressure field (cylindrical)

Total pressure at `(r, z)`:

$$\boxed{P(r,z) = P_0 + \underbrace{\rho g z}_{\text{z-hydro}} + \underbrace{\tfrac{1}{2}\rho\omega^2 r^2}_{\text{spin}} + \underbrace{\Pi_{\mathrm{osm}}(r,z)}_{\text{brine motor}}}$$

### 3.1 z-component (Z-Hydro)

Vertical hydraulic head:

$$P_z = \rho g h_{\mathrm{eff}}$$

Axial draw harvests energy where `∂P/∂z` couples to permeate upwelling — **pressurized flux brought up through the water column**.

### 3.2 Spin component

Centrifugal head at radius `r`:

$$P_\omega = \tfrac{1}{2}\rho\omega^2 r^2$$

Example: `ω = 100 rad/s`, `r = 0.15 m`, `ρ = 1020 kg/m³` → `P_ω ≈ 1.1 MPa` (illustrative; bench RPM must respect membrane mechanical limits).

### 3.3 Coupling

Rotation adds **rim pressure** and **interfacial shear** (Taylor–Couette class):

- Shear strips CP → synergistic with UDT/AOR.
- Centrifugal field biases brine to **outer wall** (density + `ω`).

---

## 4. Taylor–Couette osmotic cell (bench v0)

Inner cylinder: membrane drum. Outer cylinder: brine plenum. Gap width `d`. Spin rate `ω`.

$$\tau_{\mathrm{wall}} \propto \mu \frac{\omega r}{d}$$

Shear stress `τ_wall` reduces effective CP thickness `δ_C ∝ D/k_m`.

**Bench v0:** rotating `sgh1_membrane_housing` class drum — compare flat vs `ω > 0` at same ΔP.

---

## 5. Halocline vortex (scale-up)

At basin scale:

- **Ekman pumping** at rotating interface drives vertical exchange.
- **Stratification** stabilizes brine under fresh.
- **Coriolis** (field scale) may supplement spin stability — not required on bench.

**World win** (deployment): every desal **outfall node** in a fleet — not one literal planet-sized vortex.

---

## 6. VOH power model

Combined extractable pressure head:

$$\Delta P_{\mathrm{VOH}} = \Delta P_{\mathrm{osm}} + \rho g \Delta h_z + \tfrac{1}{2}\rho\omega^2 r_{\mathrm{eff}}^2 - \Delta P_{\mathrm{loss}}$$

Power density (illustrative):

$$P''_{\mathrm{VOH}} \approx \eta \,\Delta P_{\mathrm{VOH}} \cdot \frac{Q_{\mathrm{permeate}}}{A_{\mathrm{mem}}}$$

Full skid:

$$P_{\mathrm{net,VOH}} = P_{\mathrm{VOH}} + P_{\mathrm{AEH}} - P_{\mathrm{UDT}} - P_{\mathrm{spin\_motor}} - P_{\mathrm{pump}} - P_{\mathrm{aux}} + P_{\mathrm{px}}$$

`P_spin_motor` = mechanical cost to sustain `ω`.

---

## 7. Civilization-scale resource (honest)

From [math/REAL_WORLD_DATA.md](math/REAL_WORLD_DATA.md):

- Perth-class mixing energy order **~30 GWh/year** (theoretical, one site).
- Global brine discharge **~142×10⁶ m³/day** (UNESCO-class cite in vision docs).

VOH does not create this energy — it **recovers a fraction** before entropy dissipates.

**Fleet amplifier:** N plants × duty cycle × `η_recovery` → **GWh–TWh/year** addressable if fouling and parasitics solved.

**Not sun-equivalent W/m²** on acoustic or membrane footprint alone.

---

## 8. Code

```bash
python -c "from simulation.vortex_osmotic_hydro import voh_state; print(voh_state())"
```

Module: `simulation/vortex_osmotic_hydro.py`

Experiment: **E16** → `vision_stack.voh`

Sweep: `P_net` vs `ω` at fixed `Δπ`, `Δh_z`.

---

## 9. Hardware roadmap

| Component | CAD | Status |
|---|-----|---|
| Spinning membrane drum | extend `sgh1_membrane_housing` | bench v0 |
| z-leg draw | `sgh1_z_pipe.scad` | planned |
| Vortex basin | `sgh1_vortex_basin.scad` | planned |
| Motor / seal | BOM TBD | T1c |

---

## 10. Validation (T1c)

| Run | Config |
|-----|---|
| A | Flat stack, no spin |
| B | VOH drum, `ω = ω_1` |
| C | VOH + AOR + UDT full chain |

Pass: `P_net(C) > P_net(B) > P_net(A)` at **≥ 1 h** on 80–140 g/L brine simulant.

Log: `ω`, `ΔP`, `Q`, conductivity ×2, `P_spin_motor`, CSV export.

---

## 11. Relation to hydroelectricity

VOH **complements** river hydro:

- **River hydro:** gravitational potential of freshwater inventory.
- **VOH:** chemical potential of **salinity gradients** at coastal infrastructure, optionally plus small head and spin.

Pitch: **"Z-Hydro — hydroelectricity where there is no river, only brine."**

---

*See also: [UDT_PHYSICS.md](UDT_PHYSICS.md), [SGH1_TEST_PROTOCOL.md](SGH1_TEST_PROTOCOL.md)*

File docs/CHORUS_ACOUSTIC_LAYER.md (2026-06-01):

# CHORUS-AEH Acoustic Layer

## Mode A — Harvest

$I = p_\mathrm{rms}^2 / (\rho c)$, $P = \eta I A$.

See `simulation/acoustic_harvest.py`.

| SPL (dB) | ~Intensity | 0.5 m² @ 2% η |
|---|---|---|
| 80 | ~10⁻⁵ W/m² | µW |
| 90 | ~10⁻⁴ W/m² | tens µW |
| 96 (plant) | higher | mW class |

## Mode B — Enhance

Ultrasonic CP reduction: flux gain $g$ → net gain $P_\mathrm{PRO}(g) - P_\mathrm{US} - P_0$.

See `simulation/ultrasonic_cp_gain.py`.

## CAD

`hardware/openscad/chorus_aeh_panel.scad`

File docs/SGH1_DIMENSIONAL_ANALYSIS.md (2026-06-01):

# SGH-1 Dimensional Analysis

## Governing groups

| Symbol | Definition | Use |
|---|---|-----|
| $\Pi_1$ | $\Delta P / \Delta\pi$ | Pressure ratio — operate 0.4–0.6 |
| $\Pi_2$ | $J_w \sqrt{\rho/\Delta\pi}$ | Water flux vs osmotic driving force |
| $\Pi_3$ | $Pe = v L / D$ | Salt leakage vs advection |
| $\Pi_4$ | $P'' A / P_\mathrm{target}$ | Area scale law |

## Scale law (area)

$$A_\mathrm{mem} = \frac{P_\mathrm{target}}{P''_\mathrm{design}}$$

Default $P''_\mathrm{design} = 15\ \mathrm{W/m^2}$ (estuary RED anchor; tune from bench).

## Hydraulic

$$\Delta\pi = iRT(c_\mathrm{draw} - c_\mathrm{feed})$$
$$\Delta P^* = \frac{\Delta\pi}{2}$$

## Simulator

```bash
python simulation/run_sizing.py --power 50 --density 15
```

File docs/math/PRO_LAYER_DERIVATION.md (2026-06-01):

# Layer F — Pressure-Retarded Osmosis on Anthropogenic Brine (SGH-1)

Executable counterparts: `simulation/pro_cycle.py`, `simulation/membrane_transport.py`, `notebooks/SGH1_PRO_simulation.ipynb`.

---

## F.1 Thermodynamic driving force

For NaCl with van't Hoff factor $i=2$, the osmotic pressure of a reservoir at molar concentration $c$ (mol/m³) is

$$\pi(c) = i\,R\,T\,c, \qquad T = 298.15\ \mathrm{K}.$$

The **draw** side (desalination reject brine, $c_d \approx 1400$ mol/m³) and **feed** side (treated wastewater, $c_f \approx 5$ mol/m³) give

$$\boxed{\Delta\pi = i R T (c_d - c_f).}$$

**SGH-1 design point:** $\Delta\pi = 6.916\ \mathrm{MPa}$ (34.6 bar class), versus estuary RED $\Delta\pi \approx 2.88\ \mathrm{MPa}$ at $c_\mathrm{sea}=600$, $c_\mathrm{river}=20$ mol/m³.

The corresponding single-pair Nernst potential (informational; PRO power is hydraulic in this model) is

$$E_N = \frac{R T}{F} \ln\frac{c_d}{c_f} \approx 118\ \mathrm{mV}\quad (c_d/c_f = 280).$$

---

## F.2 Water transport and optimal hydraulic pressure

Solution-diffusion water flux (permeability $L_p$, m/(Pa·s)):

$$\dot V_w = L_p\,A\,(\Delta\pi - \Delta P), \qquad \dot m_w = \rho \dot V_w.$$

At steady state, **maximum hydraulic work** on the draw side occurs near the Kim–Baker optimum:

$$\boxed{\Delta P^* = \frac{\Delta\pi}{2}.}$$

**Operating band (FR-1):** $0.4\,\Delta\pi \leq \Delta P \leq 0.6\,\Delta\pi$ → $2.77$–$4.15$ MPa for the SGH-1 brine pair.

---

## F.3 Hydraulic and equivalent electrical power

Hydraulic power extracted from the draw volume:

$$P_\mathrm{hyd} = \dot m_w\,\Delta P.$$

With membrane and hydrodynamic efficiencies $\eta_\mathrm{mem}$, $\eta_\mathrm{hyd}$:

$$\boxed{P_\mathrm{elec,eq} = \eta_\mathrm{mem}\,\eta_\mathrm{hyd}\,\dot m_w\,\Delta P, \qquad P'' = P_\mathrm{elec,eq}/A.}$$

**Default parameters:** $L_p = 1\times10^{-12}$ m/(Pa·s), $\eta_\mathrm{mem}=0.35$, $\eta_\mathrm{hyd}=0.55$, $\Delta P = 0.5\,\Delta\pi$.

At $A = 0.72$ m² this yields $P_\mathrm{elec,eq} \approx 1.7$ W ($\sim 2.4$ W/m²) — below the **10 W design target**. Closing the gap requires bench-calibrated $L_p$, additional plates, or higher effective $P''$ from literature PRO foils (see `docs/math/SKID_ENERGY_BALANCE.md`).

---

## F.4 Concentration polarization (CP)

Film model at the high-salinity wall:

$$\frac{c_w}{c_b} = \exp\left(\frac{J_w}{k_m}\right), \qquad k_m \sim D/\delta_f.$$

Effective driving-force reduction: $\Delta\pi_\mathrm{eff} = \Delta\pi / (c_w/c_b)_\mathrm{outlet}$.

**AEH Mode B (ultrasonic assist):** treat CP disruption as multiplicative gain $g$ on $L_p$:

$$P_\mathrm{net} = P_\mathrm{PRO}(g) - P_\mathrm{US} - P_0,$$

with $P_\mathrm{US} = P''_\mathrm{US}\,A$ (default $1.5$–$2.0$ W/m² driver budget). See `simulation/ultrasonic_cp_gain.py`.

---

## F.5 Salt leakage (Pe group)

Salt flux $J_s = B\,\Delta c$ competes with advection. Peclet number:

$$\Pi_3 = Pe = \frac{v\,L}{D}, \qquad v \sim J_w.$$

High $Pe$ increases draw dilution and reduces $\Delta\pi$ over time — bench protocol T1 tracks conductivity drift.

---

## F.6 RED vs PRO crosswalk

| Regime | High $c$ | Low $c$ | $\Delta\pi$ (MPa) | Primary extraction |
|---|---|---|---|---|
| Estuary RED | 600 (sea) | 20 (river) | 2.88 | Electrical (Nernst + $R_\mathrm{int}$) |
| Sidestream PRO | 1400 (brine) | 5 (WW) | 6.92 | Hydraulic ($\Delta P$ on draw) |

CHORUS column models use RED anchors for **interface** power density ($15$ W/m²); SGH-1 uses PRO for **near-term bench** at existing desal infrastructure.

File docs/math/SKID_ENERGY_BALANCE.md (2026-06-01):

# CHORUS-Skid SGH-1 — Steady-State Energy Balance

## 1. Production terms

| Term | Symbol | Typical (model) | Notes |
|---|---|---|---|
| PRO equivalent | $P_\mathrm{PRO}$ | 1.7 W | `pro_cycle.py`, default $L_p$ |
| AEH harvest (Mode A) | $P_\mathrm{AEH}$ | 0.1–5 mW | 96 dB, $\eta=2\%$, 0.5 m² panel |
| Ultrasonic net (Mode B) | $P_\mathrm{US,net}$ | TBD | $P(g) - P_\mathrm{US} - P_0$ |

## 2. Parasitic loads (not yet in `pro_cycle.py`)

| Load | Estimate | Action |
|---|---|---|
| Feed pump | $P_p \approx Q\,\Delta P_p/\eta_p$ | Add to `simulation/parasitics.py` |
| Draw circulation | Low if gravity-fed | P&ID dependent |
| DAQ + control | < 2 W | `daq/logger.py` budget |
| US driver @ 28 kHz | 1.5–2 W/m² × $A$ | Subtracted in `ultrasonic_cp_gain.py` |

## 3. Net skid power (definition)

$$\boxed{P_\mathrm{net} = P_\mathrm{PRO} + P_\mathrm{AEH} + P_\mathrm{US,net} - P_\mathrm{pump} - P_\mathrm{aux}.}$$

**PoC honesty:** Published 10 W is a **design target** and area scale law, not a validated bench result until T1 completes.

## 4. Column context (1 km²)

From `exports/chorus_results.json` Monte Carlo ($N=8000$):

$$P_\mathrm{column,median} = 22.76\ \mathrm{MW}, \quad P_{10}=19.63,\quad P_{90}=26.46\ \mathrm{MW}.$$

Layer medians (notebook §VII): PV–hydro dominates; blue energy $\sim 0.26$ MW on estuary interface area assumptions.

## 4. Conservation check

$$\sum_k P_k \leq \sum_j \dot E_{j,\mathrm{in}} - \dot S T$$

No layer claims over-unity; TSC routes charge between high-impedance harvesters (see `CHORUS_MATH_PLAN.md` §5).

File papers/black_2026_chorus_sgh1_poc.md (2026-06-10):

# CHORUS-Skid SGH-1: Brine-Gradient Power, UDT/AOR/VOH Vision Stack, and Osmotic-Vortex Hydro

**Joseph Black** and **Connor White**  
*CHORUS Research — differential-harness*  
Full technical report · Draft v5 · June 2026

---

## Abstract

Coastal and inland desalination plants discharge hypersaline brine while treated effluent remains at near-fresh salinity. The resulting **salinity-gradient resource** is routinely dissipated as mixing entropy rather than converted to useful work. We present **CHORUS** (*Columnar Harvest of Osmotic, Rhizospheric, Orographic, and Solar flux*) as a multi-physics accounting framework for a 1 km² coastal parcel, **CHORUS-Skid SGH-1** as a bench-scale **pressure-retarded osmosis (PRO)** harness, and a three-layer **vision stack**: **UDT** (Universal Differential Tink), **AOR** (Acoustic-Osmotic Ram), and **VOH** (Vortex-Osmotic Hydro / Z-Hydro) targeting osmotic-vortex hydro at desal outfalls.

Using van't Hoff thermodynamics, Kim–Baker optimal hydraulic pressure, solution-diffusion transport, concentration-polarization film theory, and executable vision modules, we derive a consistent sizing pipeline (Δπ = 6.92 MPa, ΔP* = 34.6 bar, A_mem = 0.72 m²) and report experiments E1–E16. A **T0–T1c bench validation pipeline** (`bench_validation.py`, `run_test_protocol.py`) produces pass/fail artifacts from CSV. Column-scale Monte Carlo (N = 8000) yields median **22.76 MW/km²** (PV-dominated). Default L_p predicts **1.66 W** vs 10 W design target; L_p* ≈ 6.0×10⁻¹² m/(Pa·s) for bench closure.

**Keywords:** pressure-retarded osmosis; salinity-gradient power; UDT; AOR; VOH; Z-Hydro; osmotic-vortex hydro; bench validation

---

## Vision stack (UDT / AOR / VOH)

| Layer | Physics | Module |
|---|---|---|
| **UDT** | Ray field + particle bytes → Tink kernel → k_m,eff | `differential_tink.py` |
| **AOR** | Resonant column + brine motor + ram pipe | `acoustic_osmotic_ram.py` |
| **VOH** | Spin + halocline + z-leg pressurized flux | `vortex_osmotic_hydro.py` |

Master index: [docs/VISION.md](../docs/VISION.md)

**Pitch:** Sound strips the membrane. Brine propels the loop. Spin and the z-pipe amplify. Fleet at outfalls scales to civilization impact.

---

## Bench validation (T0–T1c)

| Stage | Pass |
|---|---|
| T0 | No leaks @ 3 bar; 15 min positive signal |
| T1 | P'' ±30% sim; P_net > 0 for 1 h |
| T1b | P_net(C) > P_net(B) > P_net(A) — UDT/AOR |
| T1c | P_net(ω) > P_net(0) — VOH spin |

```bash
python scripts/run_test_protocol.py --test T1
python -m simulation.bench_validation --csv data/bench/T1_*.csv
pytest tests/
```

---

## Reproduce PDF

```bash
./scripts/run_paper_pipeline.sh
# → papers/Black_2026_CHORUS_SGH1_PoC.pdf
```

---

*Correspondence: Joseph Black and Connor White, via differential-harness repository.*

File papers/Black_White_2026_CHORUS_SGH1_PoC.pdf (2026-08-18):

Black & White (2026) · CHORUS-SGH-1 · differential-harness | Page 1

## CHORUS-SGH-1: Brine-Gradient Power on a Bench Skid

A Proof-of-Concept Framework for Pressure-Retarded Osmosis on Anthropogenic Brine Gradients with UDT/AOR/VOH Vision Stack, Acoustic-Osmotic Ram, Vortex-Osmotic Hydro, Bench Validation Pipeline, and Column-Scale Multi-Physics Energy Accounting

### Joseph Black and Connor White

CHORUS Research Program · differential-harness

Full technical report · Draft v5 · June 2026

## Abstract

Anthropogenic desalination reject (1400 mol/m³) against treated effluent (5 mol/m³) creates Δπ = 6.92 MPa—2.4× estuary RED reference. We present CHORUS multi-layer column accounting, CHORUS-Skid SGH-1 PRO bench hardware, and a three-layer vision stack: UDT (Universal Differential Tink), AOR (Acoustic-Osmotic Ram), and VOH (Vortex-Osmotic Hydro / Z-Hydro) for osmotic-vortex hydro at coastal outfalls.
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

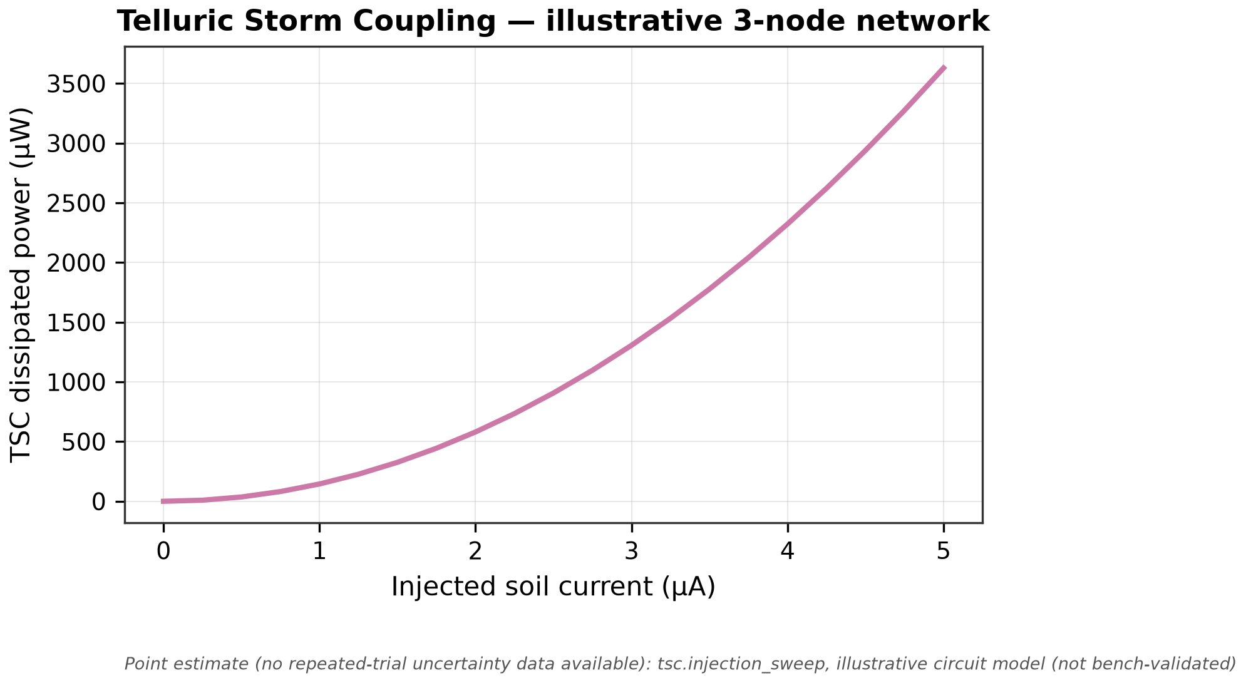
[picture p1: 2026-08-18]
exports/figures/fig11_tsc_injection.png

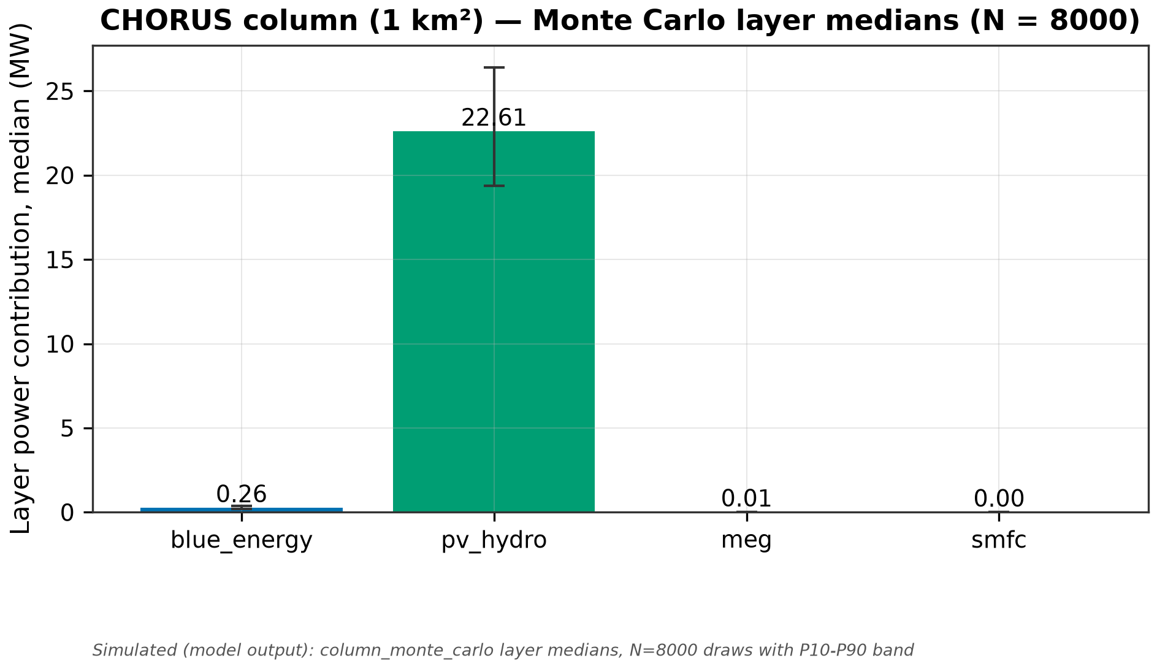
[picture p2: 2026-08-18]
exports/figures/fig03_column_layers.png

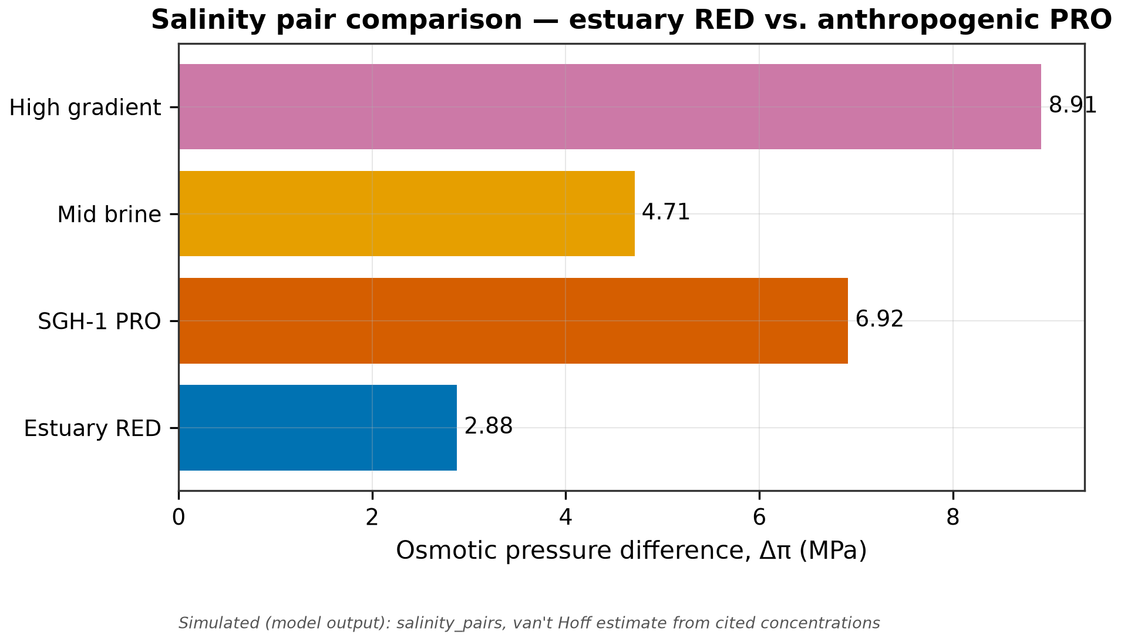
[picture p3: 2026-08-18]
exports/figures/fig07_salinity_pairs.png

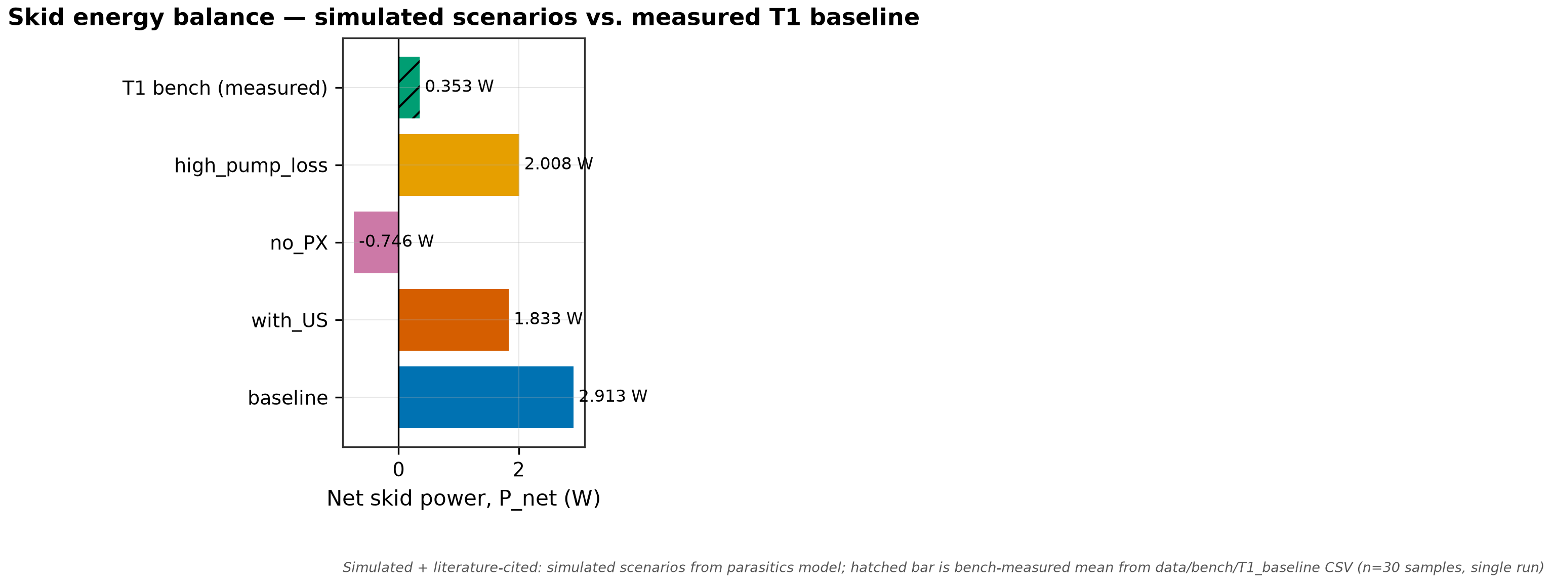
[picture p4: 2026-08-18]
exports/figures/fig10_net_energy.png

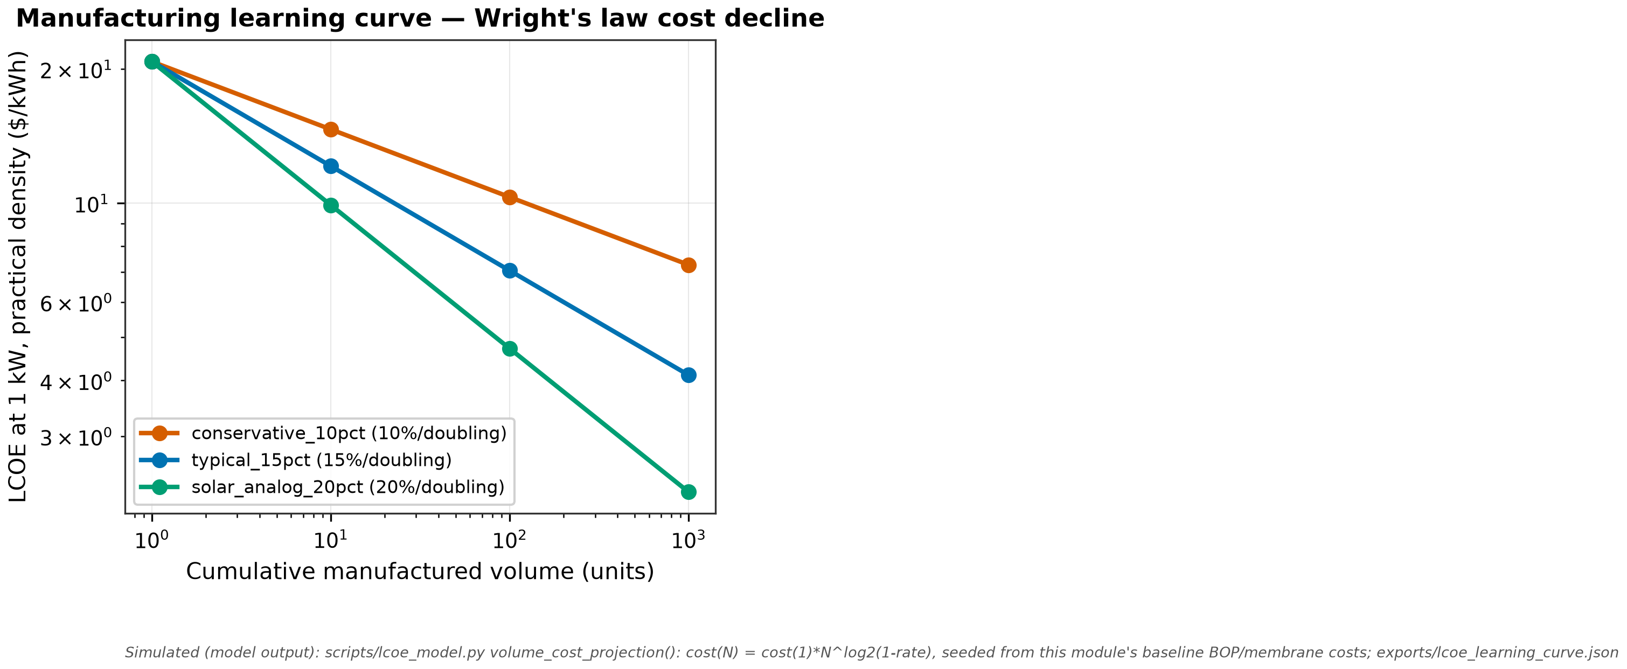
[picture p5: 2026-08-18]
exports/figures/fig18_lcoe_learning_curve.png

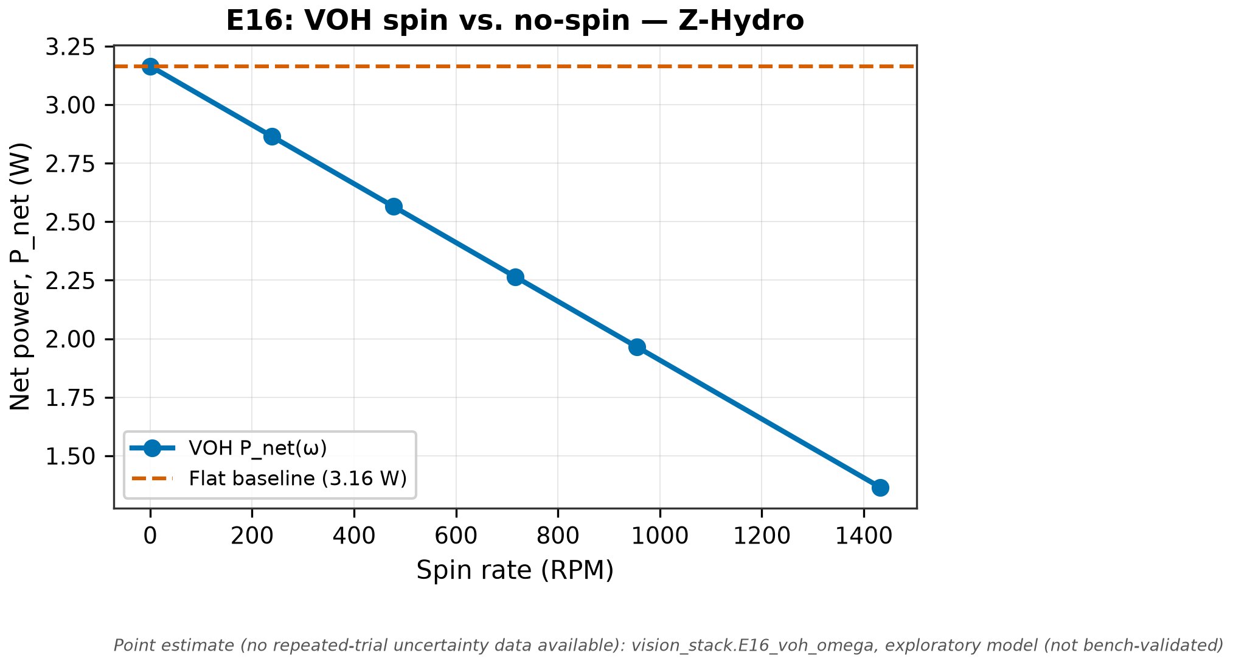
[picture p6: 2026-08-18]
exports/figures/fig16_voh_omega.png

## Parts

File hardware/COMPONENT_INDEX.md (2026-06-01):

# CHORUS-SGH-1 Component Index (complete)

## PRO fluid path

| ID | OpenSCAD | STL | Notes |
|----|---|-----|---|
| PRO-01 | `sgh1_membrane_housing.scad` | ✓ | Stack shell |
| PRO-02 | `sgh1_membrane_plate.scad` | ✓ | Spacer + window |
| PRO-03 | `sgh1_end_cap.scad` | ✓ | Qty 2 (feed + draw) |
| PRO-04 | `sgh1_pressure_vessel_ring.scad` | ✓ | Qty 2 |
| PRO-05 | `sgh1_manifold_feed.scad` | ✓ | Low salinity |
| PRO-06 | `sgh1_manifold_draw.scad` | ✓ | High pressure |
| PRO-07 | `sgh1_px_module.scad` | ✓ | Pressure work recovery |
| PRO-08 | `sgh1_turbine_housing.scad` | ✓ | Pelton / generator mount |
| PRO-09 | `sgh1_relief_valve_block.scad` | ✓ | Safety |

## CHORUS / AEH

| ID | OpenSCAD | Notes |
|----|---|---|
| CHOR-01 | `chorus_skid_enclosure.scad` | Thermal/moist plenum |
| AEH-01 | `chorus_aeh_panel.scad` | 6×4 Helmholtz cells |
| AEH-02 | `sgh1_us_mount_ring.scad` | Ultrasonic clamp |

## Structure & utilities

| ID | OpenSCAD | Notes |
|----|---|---|
| STR-01 | `sgh1_skid_frame.scad` | Main frame |
| STR-02 | `sgh1_drip_tray.scad` | Brine containment |
| STR-03 | `sgh1_mount_rail.scad` | Module slide rails |
| UT-01 | `sgh1_pump_mount.scad` | Feed pump |
| UT-02 | `sgh1_sensor_bracket.scad` | DAQ |
| UT-03 | `sgh1_feed_tank_adapter.scad` | Tank top fitting |
| UT-04 | `sgh1_brine_tank_adapter.scad` | Brine return |
| UT-05 | `sgh1_flange_adapter.scad` | 2" tri-clamp style |

## v2 module

| ID | OpenSCAD | Notes |
|----|---|---|
| RED-01 | `sgh1_red_cartridge_v2.scad` | Swap-in RED stack |

## Assemblies

| File | Purpose |
|---|---|
| `sgh1_assembly.scad` | Installed layout |
| `sgh1_exploded_assembly.scad` | Exploded view for docs |

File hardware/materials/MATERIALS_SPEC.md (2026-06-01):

# Materials Specification

| Component | Material | Grade / note |
|---|---|---|
| Draw manifold | SS316L | NACE MR0175 optional for brine |
| Feed manifold | PP-H or SS316 | Chemical compat |
| Housing shell | SS316L or HDPE | HDPE bench only ≤80°C |
| End caps | SS316L | Machined |
| Frame | 6061-T6 Al extrusion | Anodize optional |
| O-rings | Viton FKM | NaCl brine |
| Membrane | Commercial FO/PRO flat sheet | Per OEM |
| Plates/spacers | HDPE or PP | CNC |
| AEH panel | PETG/PLA + PVDF film | Non-structural |
| Drip tray | PP weld or HDPE thermoform | |

## Fasteners

- Frame: M8 hex, SS
- Housing: M6 × 45 cap screw, SS, 8× bolt circle

## Surface finish

- Sealing faces Ra ≤ 1.6 µm
- Non-seal machined Ra ≤ 3.2 µm

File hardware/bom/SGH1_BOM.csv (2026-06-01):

part_id | name | qty | material | process | supplier_notes | openscad_file
FRAME-001 | 8020 extrusion 40x40mm | 12m | 6061-T6 aluminum | cut至frame_L/W/H | McMaster 8481T41 | sgh1_skid_frame
FRAME-002 | Skid foot pad | 4 | rubber/mount | mold | generic 50mm foot | sgh1_skid_frame
HOUS-001 | Membrane housing shell | 1 | SS316L or HDPE | CNC or FDM | sgh1_membrane_housing
HOUS-002 | End cap feed | 1 | SS316L | CNC | sgh1_end_cap
HOUS-003 | End cap draw | 1 | SS316L | CNC | mirror feed cap
HOUS-004 | Pressure ring | 2 | SS316L | CNC | sgh1_pressure_vessel_ring
MEM-001 | Membrane plate/spacer | 1 | HDPE+CNC | Protomold or in-house | sgh1_membrane_plate
MEM-002 | Commercial PRO/FO membrane sheet | 1 | composite OEM | DuPont/Hydranautics FO module
MEM-003 | Viton O-ring housing | 2 | rubber | size per housing OD
MANF-001 | Feed manifold | 1 | PP or SS316 | CNC | sgh1_manifold_feed
MAND-001 | Draw manifold rated pressure | 1 | SS316 | CNC | sgh1_manifold_draw
PUMP-001 | Low-sal feed pump | 1 | 12V diaphragm | 3-5 L/min
PUMP-002 | Prefilter 10um | 1 | polypropylene | inline
PX-001 | Pressure exchanger or needle valve test loop | 1 | SS316 | optional for bench
SENS-001 | Pressure transducer 0-40 bar | 2 | piezo | draw + feed
SENS-002 | Conductivity probe | 2 | SS | K=1.0
SENS-003 | Flow meter | 2 | magnetic or turbine
DAQ-001 | Raspberry Pi 4 + ADC HAT | 1 | electronics | Adafruit/MCP3008
CHOR-001 | Thermal plenum enclosure | 1 | HDPE/PP | FDM | chorus_skid_enclosure
AEH-001 | Acoustic panel with Helmholtz cells | 1 | PLA+PVDF | FDM+bond piezo | chorus_aeh_panel
AEH-002 | PVDF piezo film 25um | 24 | polymer | Digikey LDT1-028K | chorus_aeh_panel
AEH-003 | Ultrasonic transducer 28kHz | 1 | PZT | feed CP assist
ELEC-001 | Rectifier + supercap 5F | 1 | electronics | AEH harvest
FAST-001 | M6 stainless bolt kit | 1 | SS316
FAST-002 | FNPT fittings kit | 1 | SS/PP | 1/2 and 3/4 inch
PX-002 | PX module body | 1 | SS316 | CNC | sgh1_px_module
TURB-001 | Turbine test housing | 1 | Al/SS | optional bench | sgh1_turbine_housing
SAFE-001 | Relief valve block | 1 | SS316 | set 1.2x DP* | sgh1_relief_valve_block
STR-003 | Drip tray | 1 | PP | weld | sgh1_drip_tray
STR-004 | Mount rails | 2 | Al extrusion | sgh1_mount_rail
TANK-001 | Feed drum adapter | 1 | PP | sgh1_feed_tank_adapter
TANK-002 | Brine drum adapter | 1 | PP | sgh1_brine_tank_adapter
FIT-001 | Tri-clamp flange 2in | 4 | SS316 | sgh1_flange_adapter
AEH-004 | US mount ring | 1 | Al | sgh1_us_mount_ring
RED-001 | RED cartridge v2 | 1 | prototype | sgh1_red_cartridge_v2
TUB-001 | 1/2 SS braided hose 3m | 4 | hose | feed/draw/PX
TUB-002 | 3/4 brine return hose 2m | 2 | hose
EST-001 | Estimated bench BOM | 1 | USD | ~2500-8000 | excl membrane OEM

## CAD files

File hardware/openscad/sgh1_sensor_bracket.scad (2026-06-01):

// CHORUS-SGH-1 — DAQ / conductivity sensor bracket
include <lib/generated_constants.scad>

module sensor_bracket() {
  difference() {
    union() {
      cube([60, 40, 80]);
      translate([60, 20, 40])
        rotate([0, 90, 0])
          cylinder(h=30, d=40, center=true, $fn=48);
    }
    translate([10, 10, 10])
      cube([40, 25, 60]);
    translate([15, -1, 50])
      cylinder(h=42, d=12, $fn=24);
    translate([45, 20, -1])
      cylinder(h=10, d=6, $fn=20);
  }
}

sensor_bracket();

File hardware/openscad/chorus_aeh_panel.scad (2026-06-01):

// CHORUS-AEH — acoustic harvest panel (Helmholtz resonators + piezo pocket)
include <lib/generated_constants.scad>

panel_w = frame_W * 0.6;
panel_h = 400;
panel_t = 28;
n_resonators_x = 6;
n_resonators_y = 4;
neck_d = 8;
cavity_d = 35;

module helmholtz_cell(x, y) {
  translate([x, y, 0]) {
    cylinder(h=panel_t, d=cavity_d, $fn=48);
    translate([0, 0, panel_t])
      cylinder(h=12, d=neck_d, $fn=32);
    // piezo pocket on back
    translate([0, 0, -4])
      cylinder(h=4.5, d=20, $fn=32);
  }
}

module aeh_panel() {
  difference() {
    cube([panel_w, panel_t, panel_h]);
  }
  step_x = panel_w / (n_resonators_x + 1);
  step_z = panel_h / (n_resonators_y + 1);
  for (ix = [1:n_resonators_x], iz = [1:n_resonators_y]) {
    helmholtz_cell(ix*step_x, iz*step_z);
  }
  // US transducer mount (Mode B) — feed-side assist
  translate([panel_w - 50, panel_t, panel_h/2])
    rotate([-90, 0, 0])
      cylinder(h=20, d=45, $fn=48);
  // wiring channel
  translate([10, panel_t/2, 10])
    cube([panel_w-20, 6, 12]);
}

module aeh_panel_part() { aeh_panel(); }
aeh_panel_part();

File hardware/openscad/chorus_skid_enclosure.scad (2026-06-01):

// CHORUS — thermal / moist coupling plenum (wraps PRO housing)
include <lib/generated_constants.scad>

module chorus_enclosure() {
  plenum_gap = 25;
  wall = 4;
  len = housing_len + 80;
  od = housing_od + 2*plenum_gap;
  difference() {
    translate([0, 0, 30])
      cylinder(h=len, d=od, $fn=80);
    translate([0, 0, 30+wall])
      cylinder(h=len, d=od-2*wall, $fn=72);
    // humidity inlet louvers
    for (z = [60:40:len]) {
      rotate([0, 0, 30])
        translate([od/2-2, 0, z])
          cube([10, 40, 8], center=true);
    }
    // PV/moist panel mount rail (top)
    translate([-od/2, -30, len+20])
      cube([od, 60, 8]);
  }
  // sensor gland plate
  translate([od/2+5, 0, len/2+30])
    cube([8, 80, 40], center=true);
}

module chorus_enclosure_part() { chorus_enclosure(); }
chorus_enclosure_part();

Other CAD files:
hardware/openscad/sgh1_assembly.scad
hardware/openscad/sgh1_brine_tank_adapter.scad
hardware/openscad/sgh1_drip_tray.scad
hardware/openscad/sgh1_end_cap.scad
hardware/openscad/sgh1_exploded_assembly.scad
hardware/openscad/sgh1_feed_tank_adapter.scad
hardware/openscad/sgh1_flange_adapter.scad
hardware/openscad/sgh1_manifold_draw.scad
hardware/openscad/sgh1_manifold_feed.scad
hardware/openscad/sgh1_membrane_housing.scad
hardware/openscad/sgh1_membrane_plate.scad
hardware/openscad/sgh1_mount_rail.scad
hardware/openscad/sgh1_pressure_vessel_ring.scad
hardware/openscad/sgh1_pump_mount.scad
hardware/openscad/sgh1_px_module.scad
hardware/openscad/sgh1_red_cartridge_v2.scad
hardware/openscad/sgh1_relief_valve_block.scad
hardware/openscad/sgh1_skid_frame.scad
hardware/openscad/sgh1_turbine_housing.scad
hardware/openscad/sgh1_us_mount_ring.scad

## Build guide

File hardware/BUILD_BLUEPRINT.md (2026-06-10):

# CHORUS-Skid SGH-1 + AEH-1 — Build Blueprint

Complete hardware build guide. Pair with [docs/SGH1_DEVICE_SPEC.md](../docs/SGH1_DEVICE_SPEC.md) and OpenSCAD in `openscad/`.

## 0. Generate sizing + CAD constants

```bash
cd ~/projects/differential-harness
source .venv/bin/activate
python simulation/run_sizing.py --power 50
bash hardware/scripts/export_stl.sh   # needs OpenSCAD
```

Outputs:
- `exports/sgh1_sizing.json`
- `hardware/openscad/lib/generated_constants.scad`
- `hardware/stl/*.stl`

## 1. System overview

| Subsystem | Part files | Function |
|---|---|---|
| **PRO core** | `sgh1_membrane_housing`, `sgh1_membrane_plate`, `sgh1_end_cap` ×2, `sgh1_pressure_vessel_ring` | Salinity-gradient power |
| **Fluids** | `sgh1_manifold_feed`, `sgh1_manifold_draw`, `sgh1_pump_mount` | Feed + brine + pressurized draw |
| **CHORUS frame** | `sgh1_skid_frame`, `chorus_skid_enclosure` | Mount + thermal/moist plenum |
| **AEH** | `chorus_aeh_panel` | Acoustic harvest + US mount |
| **Instruments** | `sgh1_sensor_bracket` | Conductivity / pressure / DAQ |

## 2. Build order

1. **Skid frame** — weld or bolt 40×40 aluminum extrusion per `sgh1_skid_frame.stl`; level feet.
2. **Membrane plates** — CNC HDPE/SS316 plates or print HDPE; bond commercial FO/PRO sheet per active window.
3. **Housing** — machine or print shell; install guide rails; torque end caps with Viton O-rings.
4. **Manifolds** — machine feed (low pressure) and draw (rated for `delta_P_bar` from sizing JSON).
5. **Plumb loop** — feed pump → prefilter → feed manifold → stack → draw manifold → PX/turbine test loop → brine return tank.
6. **Enclosure + AEH panel** — bolt to frame; route piezo wires to DAQ; optional US transducer on feed manifold.
7. **DAQ** — `python daq/logger.py`; verify conductivity, ΔP, flow.

## 3. Pressure rating

Design hydraulic pressure on draw side: **ΔP* ≈ Δπ/2** (see `exports/sgh1_sizing.json` → `delta_P_star_bar`).

- Relief valve set at **1.2 × delta_P_star_bar**
- Hydrotest at **1.5 ×** before saline service

## 4. Fluids (bench)

| Stream | Composition (bench) | Tank |
|---|---|---|
| Feed | NaCl **5 g/L** tap water | 50 L low-sal tank |
| Draw | NaCl **80–140 g/L** (brine simulant) | 50 L high-sal tank |

**Warning:** corrosive — SS316 wetted parts, eye protection, brine containment tray on skid.

## 5. Electrical

- Turbine/alternator or pressure motor on draw loop (measure shaft power).
- AEH panel → rectifier → supercap → Raspberry Pi DAQ (optional).
- US driver: 28 kHz ultrasonic transducer, **separate** from harvest piezos.

## 6. Acceptance test

1. Zero leak hold at 1.0× ΔP* for 10 min.
2. Stable conductivity differential feed vs draw.
3. Positive hydraulic power on draw circuit OR positive electrical from turbine.
4. Log CSV 1 h; compare `P_density` to simulation ±30%.

## 7. Vision hardware (v3 — planned)

See [docs/VISION.md](../docs/VISION.md).

| Part | Purpose |
|---|---|
| `sgh1_tink_ring.scad` | Toroidal UDT ray / US mounts |
| `sgh1_z_pipe.scad` | Axial hyperspeed draw leg (Z-Hydro) |
| `sgh1_vortex_basin.scad` | Taylor–Couette / halocline cell |

Bench order after SGH-1 T1: T1b (UDT/AOR) → T1c (spinning drum).

## 8. File index (OpenSCAD)

```
hardware/openscad/
  sgh1_assembly.scad          # full layout
  sgh1_membrane_plate.scad
  sgh1_end_cap.scad
  sgh1_membrane_housing.scad
  sgh1_manifold_feed.scad
  sgh1_manifold_draw.scad
  sgh1_pressure_vessel_ring.scad
  sgh1_skid_frame.scad
  chorus_skid_enclosure.scad
  chorus_aeh_panel.scad
  sgh1_pump_mount.scad
  sgh1_sensor_bracket.scad
  lib/generated_constants.scad
  lib/utils.scad
```

Import assembly into **FreeCAD**: File → Import STL from `hardware/stl/`, assemble constraints in `hardware/freecad/SGH1_Assembly.FCStd` (create locally).

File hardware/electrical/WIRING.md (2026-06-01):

# CHORUS-SGH-1 Electrical / DAQ Wiring

## Sensor map

| Signal | Sensor | Interface | Pi channel |
|---|---|---|---|
| P_feed | 0–40 bar transducer | 4–20 mA → 250Ω | MCP3008 CH0 |
| P_draw | 0–40 bar transducer | 4–20 mA → 250Ω | CH1 |
| Q_feed | turbine flow | pulse / analog | CH2 |
| Q_draw | turbine flow | pulse / analog | CH3 |
| cond_feed | conductivity cell | analog board | CH4 |
| cond_draw | conductivity cell | analog board | CH5 |
| T_feed | NTC 10k | divider | CH6 |
| T_draw | NTC 10k | divider | CH7 |

## AEH harvest bus

```
Piezo array → bridge rectifier → supercap 5F → buck 5V → Pi USB (optional)
```

## Ultrasonic driver (isolated from harvest)

```
Sig gen 28 kHz → MOSFET driver → US transducer 50W max
Enable interlock with P_draw > threshold
```

## Pump interlock

```
Draw pressure OK + feed flow OK → enable feed pump relay
E-stop cuts all pumps + US
```

See `WIRING_DIAGRAM.txt` for ASCII layout.

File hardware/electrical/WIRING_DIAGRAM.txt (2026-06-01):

                    CHORUS-SGH-1 DAQ (Raspberry Pi 4)
                    ================================
                           [MCP3008 HAT]
     P_feed ----[4-20mA]--- CH0        CH4 --- cond_feed
     P_draw ----[4-20mA]--- CH1        CH5 --- cond_draw
     Q_feed -------------- CH2        CH6 --- T_feed
     Q_draw -------------- CH3        CH7 --- T_draw

     [USB] logger.py / dashboard.py

     AEH Panel ----[rectifier]----[5F cap]----(optional 5V buck)
     US Xducer ----[driver board]---- GPIO enable (GPIO17)

     [Relay K1] Feed pump 120VAC or 12V
     [Relay K2] E-stop NC chain

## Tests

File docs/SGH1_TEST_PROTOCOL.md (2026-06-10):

# SGH-1 Test Protocol

## T0 — Coupon / single plate

1. Leak test air @ 3 bar, 10 min.
2. Water flush both sides.
3. Establish feed 5 g/L, draw 80 g/L; record conductivity.
4. Ramp ΔP from 0 → 0.5 Δπ → 0.5 Δπ* over 30 min.
5. Log at 1 Hz (`daq/logger.py`).
6. Pass: no leaks; P_elec or hydraulic power > 0 steady 15 min.

## T1 — Full stack

1. Hydrotest draw side 1.25× ΔP* with water.
2. 1 h steady run; export CSV.
3. Compare `P_density` to simulation ±30%.

## T2 — Field sidestream

1. NDA + utility approval.
2. Tie-in to brine + effluent; same logging.

## Acoustic (AEH)

1. SPL meter at panel face; verify 80+ dB environment optional.
2. Measure harvest Voc into 1 MΩ load.
3. US on: compare flux / power vs off (Mode B).

## T1b — UDT / AOR (vision)

1. Same ΔP as T1; log 1 Hz minimum 60 min.
2. Run A: US off, incoherent driver off.
3. Run B: UDT phased rays on (see [UDT_PHYSICS.md](UDT_PHYSICS.md)).
4. Run C: full AOR — resonant column tuned to `f ≈ c/(4H)`.
5. Pass: `P_net(C) > P_net(B) > P_net(A)` OR document fouling-limited crossover.

## T1c — VOH / Z-Hydro (vision)

1. Compare flat stack (ω = 0) vs spinning drum at fixed ω (RPM logged).
2. Measure `P_spin_motor` separately.
3. Pass: `P_net(ω) > P_net(0)` after subtracting spin parasitic, same brine pair.

Vision index: [VISION.md](VISION.md)

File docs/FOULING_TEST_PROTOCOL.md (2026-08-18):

# SGH-1 Fouling Test Protocol (T1f)

Extends `docs/SGH1_TEST_PROTOCOL.md`'s T0/T1/T1b/T1c/T2 sequence with a
dedicated fouling-resistance phase, **T1f**, run after T1 (clean-water
baseline) and before any T2 field sidestream commitment.

## Why this exists — the Statkraft Tofte precedent

This is not a hypothetical concern added for completeness. The
Statkraft Tofte PRO pilot (Hurum, Norway, 2009-2014;
`docs/CANDIDATE_SITES.md` site 3) is the largest real-world PRO test to
date, and it never reached economic power density partly because of
biofouling and scaling from real river/seawater impurities — REDstack's
own multistage RED pilot autopsy after 30 days of natural water found
"mostly organic fouling at the membrane surface and spacers." A T0-T2
protocol validated only on clean bench water (which `data/bench/*.csv`
in this repo currently is — see `docs/ROADMAP.md` M6) would not have
caught the failure mode that historically killed the most comparable
real pilot. T1f exists specifically to close that gap before any real
site commitment (T2).

## Fouling mechanisms this protocol targets

1. **Organic fouling** — dissolved/colloidal organic matter (humic
   substances, proteins, polysaccharides) adsorbing to the membrane
   and support-layer pores; documented in the literature as
   particularly severe in PRO mode specifically, because flow is driven
   through the support layer in the direction that concentrates
   foulant against it.
2. **Biofouling** — microbial biofilm growth on the membrane surface,
   accelerated in real (non-sterile) feed and draw streams.
3. **Inorganic scaling** — calcium sulfate/carbonate precipitation
   where local concentration at the membrane surface (concentration
   polarization, `simulation/membrane_transport.py`) exceeds solubility.
4. **Colloidal fouling** — fine particulates (silt, clay) depositing on
   the membrane surface, distinct from dissolved organic fouling.

## T1f procedure

### T1f.1 — Synthetic foulant baseline (bench, no real hardware access required to *design* this)

Following the standard model-foulant recipes used across FO/PRO fouling
literature (no single codified ASTM-style standard exists for PRO
specifically — this protocol adapts documented research-literature
practice, stated honestly rather than presented as an established
standard):

| Foulant class | Recipe | Represents |
|---|---|---|
| Organic (alginate) | ~200 ppm sodium alginate + 1.5 mM CaCl₂ | Polysaccharide/organic fouling, calcium-alginate gel layer |
| Organic (protein) | ~1,000 ppm bovine serum albumin (BSA) | Protein fouling |
| Colloidal | Kaolin or silica suspension | Particulate/colloidal fouling |
| Scaling | CaCl₂ + Na₂SO₄ at supersaturating concentration for the draw-side salinity | Calcium sulfate/carbonate scaling |

Run each foulant class as an independent T1f sub-run, feed-side only
(draw side remains clean brine, matching how real deployments would see
foulant concentrated on the feed/dilute side).

### T1f.2 — Flux-decline measurement protocol

1. Run T1 baseline (clean feed) for the first 25% of the run (steady
   window, matching `simulation.bench_validation`'s
   `STEADY_WINDOW_FRAC`).
2. Switch feed to the foulant solution; continue logging at 1 Hz
   (`daq/logger.py`) for a minimum of 4 hours (long enough to resolve a
   flux-decline curve, short enough to be a practical bench test).
3. Use `scripts/calibrate_constants.py`'s new `fit_L_p_time_series()`
   (added in this round) to fit `L_p` in chronological sub-windows
   across the run and compute **percent L_p decline from the clean
   baseline window to the final fouled window** — this is the
   headline fouling-resistance metric.
4. Pass/fail gate (proposed, pending real calibration data): **L_p
   decline < 20% over 4 hours** is treated as an acceptable
   fouling-resistance result for continuing to T1f.3; a larger decline
   flags the membrane/geometry combination as high fouling risk before
   committing further bench time.

### T1f.3 — Cleaning-in-place (CIP) recovery test

1. After the T1f.2 fouled run, flush with a CIP solution appropriate to
   the foulant class (e.g. citric acid rinse for scaling, alkaline/
   detergent rinse for organic/biofouling — standard RO/FO CIP
   practice).
2. Re-run a clean-feed steady window and re-fit `L_p`.
3. **Recovery ratio = L_p(post-CIP) / L_p(pre-fouling baseline)**.
   A recovery ratio near 1.0 indicates the fouling was largely
   reversible (favorable for the membrane-replacement-interval
   assumption in `docs/ECONOMICS.md`); a recovery ratio well below 1.0
   indicates irreversible fouling accumulation, which would shorten the
   real membrane life below the 5-7 year RO/FO industry analog
   currently assumed there.

### T1f.4 — Reporting

Each T1f run's `bench_validation.json` / a new `fouling_report.json`
(from `fit_L_p_time_series()`) should record: foulant class, L_p decline
%, recovery ratio, and total run duration — feeding directly into
`docs/ECONOMICS.md`'s membrane-replacement-interval and capacity-factor
assumptions once real T1f data exists.

## Honest hard limits

- **This protocol has not been run against real hardware or real
  foulant solutions.** No physical bench exists in this environment
  (same limit as `docs/ROADMAP.md` M6). This document specifies a
  rigorous, literature-grounded methodology and the exact code
  (`fit_L_p_time_series()`) needed to analyze the resulting data — it
  does not, and cannot, claim any fouling-resistance result for
  CHORUS-SGH-1's actual membrane/geometry combination.
- **No PRO-specific standard foulant recipe or pass/fail threshold
  exists in the public literature** to adopt wholesale — the recipes
  and the 20%/4hr threshold above are this protocol's own reasoned
  synthesis from adjacent RO/FO fouling literature, explicitly flagged
  as such, not a citation of an established PRO fouling standard.
- **Biofouling specifically cannot be meaningfully bench-tested with
  synthetic foulant alone** — real biofouling requires real microbial
  populations from real feed water, which by definition requires a
  real site (T2), not a clean bench. T1f's synthetic-foulant runs are a
  necessary but not sufficient precursor to a real biofouling
  assessment at an actual candidate site.

## Sources

- Fouling fractionation in RED with natural feed waters, *Journal of
  Membrane Science* (ScienceDirect) — https://www.sciencedirect.com/science/article/pii/S0011916421003489
- Influences of Combined Organic Fouling and Inorganic Scaling on FO
  Flux (PMC) — https://pmc.ncbi.nlm.nih.gov/articles/PMC7345687/
- Accelerated testing for fouling of microfiltration membranes using
  model foulants (ScienceDirect) — https://www.sciencedirect.com/science/article/abs/pii/S0011916414000320
- ForwardOsmosisTech, "Is PRO economically feasible? Not according to
  Statkraft" — https://www.forwardosmosistech.com/statkraft-discontinues-investments-in-pressure-retarded-osmosis-2/

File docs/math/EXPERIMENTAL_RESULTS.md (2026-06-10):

# Numerical Experimental Results

Generated by `python -m simulation.experiments` → `exports/paper_experiments.json`.

## Reproduce

```bash
python -m simulation.experiments
python scripts/generate_paper_figures.py
python scripts/build_research_paper.py
```

## Key findings (SGH-1, T = 298.15 K)

| Experiment | Finding |
|---|---|
| E1 ΔP/Δπ sweep | Maximum P = 1.66 W at ratio 0.5 (Kim–Baker) |
| E2 L_p sweep | 10 W requires L_p ≈ 6.0×10⁻¹² m/(Pa·s) |
| E3 Salinity | Brine pair Δπ = 6.92 MPa vs estuary 2.88 MPa |
| E4 CP | At J_w = 1×10⁻⁵ m/s, ~22% driving-force loss |
| E5 Ultrasonic | Net gain positive only for g ≳ 1.5 at default parasitic |
| E6 Acoustic | 96 dB → ~2.5 mW on 0.5 m² |
| E7 Column MC | pv_hydro ~98.7% of median layer sum; blue_energy ~1.1% |
| E8–E13 | RED c_river, temperature, η_mem, slip b, net energy, TSC |
| E14 | UDT η_tink sweep → flux gain, P_net | `vision_stack.E14_udt_eta_tink` |
| E15 | AOR resonant column height vs P_net | `vision_stack.E15_aor_column_height` |
| E16 | VOH ω sweep; flat vs spin compare | `vision_stack.E16_voh_omega` |

Also: `symbolic_checks.json`, `openscad_audit.json`.

Vision physics: [../VISION.md](../VISION.md) · [../UDT_PHYSICS.md](../UDT_PHYSICS.md) · [../AOR_PHYSICS.md](../AOR_PHYSICS.md) · [../VOH_PHYSICS.md](../VOH_PHYSICS.md)

## Figures

| File | Content |
|---|---|
| fig01_pro_pressure_sweep.png | P vs ΔP/Δπ |
| fig02_Lp_sweep.png | P vs L_p |
| fig03_column_layers.png | MC layer medians |
| fig04_cp_sweep.png | CP loss vs J_w |
| fig05_ultrasonic_net.png | P_net vs g |
| fig06_acoustic_spl.png | mW vs SPL |
| fig07_salinity_pairs.png | Δπ comparison |
| fig08–fig11 | RED river, temperature, net energy, TSC |

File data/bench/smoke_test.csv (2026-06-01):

t_s | P_feed_bar | P_draw_bar | Q_feed_L_min | Q_draw_L_min | cond_feed_mS_cm | cond_draw_mS_cm | T_feed_C | T_draw_C | P_elec_W | iso_time
0.0001195069999084808 | 0.5000005975349995 | 1.4000017072428557 | 2.000004780279996 | 1.8 | 8.0 | 85.0 | 22.0 | 23.0 | 45.00002987674998 | 2026-06-01T06:08:46.895886+00:00
1.0002866250001716 | 0.504993096795636 | 1.4142412258990893 | 2.039745102557042 | 1.8 | 8.0 | 85.0 | 22.0 | 23.0 | 45.24996741302611 | 2026-06-01T06:08:47.896075+00:00

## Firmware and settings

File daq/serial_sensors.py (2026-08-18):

#!/usr/bin/env python3
"""Real serial sensor ingestion for the CHORUS-SGH-1 bench DAQ.

Talks to a bench sensor node (DAQ-001: Raspberry Pi 4 + MCP3008 ADC HAT,
per hardware/bom/SGH1_BOM.csv) over a USB-CDC serial link using the
framed, checksummed ASCII protocol defined in daq/protocol.py.

Behavior contract:
  * If --port is given, this module genuinely attempts to open it with
    pyserial and read real, checksum-validated frames.
  * On a dropped connection it reconnects with backoff, up to a bounded
    number of attempts, rather than giving up silently.
  * It falls back to simulated data (daq.logger.read_sensors_sim) ONLY
    when the port cannot be opened at all, or no valid frame arrives
    within the configured read timeout after retries -- and every such
    fallback emits a loud, repeated warning (stderr + logging), never a
    silent substitution.
  * Malformed/corrupted frames are counted and logged, not silently
    accepted or silently dropped without trace.
"""

from __future__ import annotations

import argparse
import logging
import sys
import time
import warnings
from pathlib import Path

from daq.logger import DATA, read_sensors_sim, run  # noqa: F401 (run kept for API parity)
from daq.protocol import SENTENCE_ID, VISION_SENTENCE_ID, Frame, FrameError, StreamReassembler

log = logging.getLogger("daq.serial_sensors")

try:
    import serial  # pyserial
    from serial import SerialException
except ImportError:  # pragma: no cover - exercised only when pyserial truly absent
    serial = None
    SerialException = Exception


DEFAULT_BAUD = 115200
CONNECT_TIMEOUT_S = 3.0
READ_TIMEOUT_S = 5.0
RECONNECT_ATTEMPTS = 3
RECONNECT_BACKOFF_S = 1.0


class FallbackToSimulation(RuntimeWarning):
    """Raised as a warning (not silently) whenever real hardware data is unavailable."""


def _warn_fallback(reason: str) -> None:
    msg = (
        f"[daq.serial_sensors] FALLING BACK TO SIMULATED DATA: {reason}. "
        "No real sensor data is being recorded for this sample."
    )
    warnings.warn(msg, FallbackToSimulation, stacklevel=3)
    log.warning(msg)
    print(f"WARNING: {msg}", file=sys.stderr)


class SerialLink:
    """Owns a pyserial connection plus frame reassembly and reconnect logic."""

    def __init__(
        self,
        port: str,
        baud: int = DEFAULT_BAUD,
        connect_timeout: float = CONNECT_TIMEOUT_S,
        read_timeout: float = READ_TIMEOUT_S,
        reconnect_attempts: int = RECONNECT_ATTEMPTS,
        reconnect_backoff: float = RECONNECT_BACKOFF_S,
    ) -> None:
        if serial is None:
            raise RuntimeError(
                "pyserial is not installed; install it with `pip install pyserial` "
                "to use real serial ingestion"
            )
        self.port = port
        self.baud = baud
        self.connect_timeout = connect_timeout
        self.read_timeout = read_timeout
        self.reconnect_attempts = reconnect_attempts
        self.reconnect_backoff = reconnect_backoff
        self._reasm = StreamReassembler()
        self._conn: "serial.Serial | None" = None
        self.frames_ok = 0
        self.frames_bad = 0
        self._pending: list[Frame] = []  # frames read but not yet consumed by the caller

    def open(self) -> bool:
        """Attempt to open the serial port. Returns True on success, False otherwise."""
        try:
            self._conn = serial.Serial(
                port=self.port,
                baudrate=self.baud,
                timeout=self.read_timeout,
                write_timeout=self.connect_timeout,
            )
            log.info("Opened serial port %s @ %d baud", self.port, self.baud)
            return True
        except (SerialException, OSError) as exc:
            log.error("Failed to open serial port %s: %s", self.port, exc)
            self._conn = None
            return False

    def close(self) -> None:
        if self._conn is not None:
            try:
                self._conn.close()
            except Exception:  # pragma: no cover - best-effort close
                pass
            self._conn = None

    def _reconnect(self) -> bool:
        for attempt in range(1, self.reconnect_attempts + 1):
            log.warning(
                "Serial link to %s lost; reconnect attempt %d/%d",
                self.port,
                attempt,
                self.reconnect_attempts,
            )
            self.close()
            time.sleep(self.reconnect_backoff * attempt)
            if self.open():
                return True
        return False

    def read_frame(self, deadline_s: float | None = None, sentence_id: str | None = None) -> Frame | None:
        """Block (up to deadline_s, or self.read_timeout if None) for one valid frame.

        The serial link multiplexes multiple sentence types ($SGH1 process
        sensors, $SGHV vision-stack sensors) on one connection. If
        `sentence_id` is given, only a frame of that type is returned;
        frames of other types encountered while waiting are buffered in
        `self._pending` so a subsequent call (for the other sentence id)
        can still consume them without re-reading the port.

        Returns None if the deadline elapses without a matching valid
        frame (caller should then fall back to simulation with an
        explicit warning).
        """
        if self._conn is None:
            return None

        for i, frame in enumerate(self._pending):
            if sentence_id is None or frame.sentence_id == sentence_id:
                return self._pending.pop(i)

        deadline = time.monotonic() + (deadline_s if deadline_s is not None else self.read_timeout)
        while time.monotonic() < deadline:
            try:
                raw = self._conn.readline()
            except (SerialException, OSError) as exc:
                log.error("Serial read error on %s: %s", self.port, exc)
                if not self._reconnect():
                    return None
                continue

            if not raw:
                # readline() timed out with no data -- keep waiting until deadline
                continue

            for result in self._reasm.feed(raw):
                if isinstance(result, FrameError):
                    self.frames_bad += 1
                    log.warning("Dropped malformed frame from %s: %s", self.port, result)
                    continue
                self.frames_ok += 1
                if sentence_id is None or result.sentence_id == sentence_id:
                    return result
                self._pending.append(result)  # not the type we're waiting for; save it
        return None


def read_sensors_serial(
    t: float,
    port: str | None,
    link: SerialLink | None = None,
) -> dict[str, float]:
    """Return one sensor row, sourced from real hardware when possible.

    `link` may be pre-opened by the caller (e.g. main()) so a single
    SerialLink/connection is reused across samples instead of reopening
    the port every call.
    """
    if not port:
        _warn_fallback("no --port configured")
        row = read_sensors_sim(t)
        row["data_source"] = "simulated"
        return row

    if link is None or link._conn is None:
        _warn_fallback(f"could not open or maintain serial port {port!r}")
        row = read_sensors_sim(t)
        row["data_source"] = "simulated"
        row["serial_port"] = port
        return row

    frame = link.read_frame(sentence_id=SENTENCE_ID)
    if frame is None:
        _warn_fallback(
            f"no valid $SGH1 frame received from {port!r} within {link.read_timeout}s "
            f"(ok={link.frames_ok}, bad={link.frames_bad})"
        )
        row = read_sensors_sim(t)
        row["data_source"] = "simulated"
        row["serial_port"] = port
        return row

    row = dict(frame.values)
    row["data_source"] = "hardware"
    row["serial_port"] = port
    row["frame_seq"] = frame.seq
    return row


def _vision_sensors_sim(t: float) -> dict[str, float]:
    """Simulated fallback for the vision-stack ($SGHV) sensor node.

    There is no real acoustic/vortex hardware attached in this
    environment (docs/ROADMAP.md M7); this is a clearly-labeled
    simulated placeholder consistent in shape with daq.protocol's
    VISION_FIELD_NAMES, used only so downstream tooling has a value to
    consume when no vision-stack node answers.
    """
    import math

    return {
        "us_amplitude_mV": 250.0 + 15.0 * math.sin(t / 9),
        "us_phase_deg": 0.0,
        "piezo_array_V": 1.2 + 0.1 * math.sin(t / 6),
    }


def read_vision_sensors_serial(
    t: float,
    port: str | None,
    link: SerialLink | None = None,
) -> dict[str, float]:
    """Return one $SGHV (vision-stack) sensor row, sourced from real
    hardware when possible, falling back loudly to simulation otherwise.

    Mirrors read_sensors_serial's contract exactly, but for the
    AEH-003 ultrasonic transducer / AEH-002 PVDF piezo array sentence.
    """
    if not port:
        _warn_fallback("no --port configured for vision-stack sensor node")
        row = _vision_sensors_sim(t)
        row["data_source"] = "simulated"
        return row

    if link is None or link._conn is None:
        _warn_fallback(f"could not open or maintain serial port {port!r} for vision-stack node")
        row = _vision_sensors_sim(t)
        row["data_source"] = "simulated"
        row["serial_port"] = port
        return row

    frame = link.read_frame(sentence_id=VISION_SENTENCE_ID)
    if frame is None:
        _warn_fallback(
            f"no valid $SGHV frame received from {port!r} within {link.read_timeout}s "
            f"(ok={link.frames_ok}, bad={link.frames_bad})"
        )
        row = _vision_sensors_sim(t)
        row["data_source"] = "simulated"
        row["serial_port"] = port
        return row

    row = dict(frame.values)
    row["data_source"] = "hardware"
    row["serial_port"] = port
    row["frame_seq"] = frame.seq
    return row


def main() -> None:
    p = argparse.ArgumentParser(description="Real (or explicitly-fallback) serial sensor logger")
    p.add_argument("--port", type=str, default=None, help="e.g. /dev/ttyUSB0")
    p.add_argument("--baud", type=int, default=DEFAULT_BAUD)
    p.add_argument("--duration", type=float, default=60)
    p.add_argument("--interval", type=float, default=1.0)
    p.add_argument("--read-timeout", type=float, default=READ_TIMEOUT_S)
    args = p.parse_args()

    logging.basicConfig(level=logging.INFO, format="%(asctime)s %(levelname)s %(message)s")

    stamp = time.strftime("%Y%m%d_%H%M%S")
    out = DATA / f"serial_{stamp}.csv"

    link: SerialLink | None = None
    if args.port:
        try:
            link = SerialLink(args.port, baud=args.baud, read_timeout=args.read_timeout)
            if not link.open():
                _warn_fallback(f"failed to open {args.port!r} at startup")
                link = None
        except RuntimeError as exc:
            _warn_fallback(str(exc))
            link = None

    t0 = time.monotonic()
    import csv

    fields = list(read_sensors_sim(0).keys()) + [
        "iso_time",
        "serial_port",
        "data_source",
        "frame_seq",
    ]
    DATA.mkdir(parents=True, exist_ok=True)
    with out.open("w", newline="", encoding="utf-8") as f:
        w = csv.DictWriter(f, fieldnames=fields, extrasaction="ignore")
        w.writeheader()
        while time.monotonic() - t0 < args.duration:
            t = time.monotonic() - t0
            from datetime import datetime, timezone

            row = read_sensors_serial(t, args.port, link=link)
            row["iso_time"] = datetime.now(timezone.utc).isoformat()
            w.writerow(row)
            f.flush()
            time.sleep(args.interval)

    if link is not None:
        link.close()
    print(f"Wrote {out}")


if __name__ == "__main__":
    main()

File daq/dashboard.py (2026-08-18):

#!/usr/bin/env python3
"""Lightweight live dashboard for an in-progress daq/logger.py bench session.

Deliberately stdlib-only (http.server + json), matching pyproject.toml's
zero-extra-dependency footprint -- no Flask/websocket dependency is
introduced. The server tails the target bench CSV on every request (a
CSV file being actively appended to by daq/logger.py or
daq/serial_sensors.py) and serves:

  * GET /api/latest  -> JSON of the most recent row + a bounded window
                        of recent rows for sparklines
  * GET /             -> a small polling HTML page rendering the above

Usage:
    python -m daq.dashboard --csv data/bench/T1_baseline_20260609_235853.csv --port 8765
"""

from __future__ import annotations

import argparse
import csv
import json
import threading
from http.server import BaseHTTPRequestHandler, ThreadingHTTPServer
from pathlib import Path
from urllib.parse import urlparse

DEFAULT_WINDOW = 120  # rows kept for sparklines
SPARKLINE_FIELDS = [
    "P_feed_bar",
    "P_draw_bar",
    "Q_feed_L_min",
    "Q_draw_L_min",
    "P_elec_W",
    "P_net_W",
]

PAGE_TEMPLATE = """<!doctype html>
<html>
<head>
<meta charset="utf-8">
<title>CHORUS-SGH-1 Bench Dashboard</title>
<meta http-equiv="refresh" content="0">
<style>
  body {{ font-family: monospace; background:#111; color:#eee; margin:2rem; }}
  h1 {{ font-size: 1.1rem; color:#8fd; }}
  table {{ border-collapse: collapse; margin-top: 1rem; }}
  td, th {{ padding: 0.25rem 0.75rem; border-bottom: 1px solid #333; text-align: right; }}
  th {{ color:#8fd; }}
  .stale {{ color: #f66; }}
</style>
</head>
<body>
<h1>CHORUS-SGH-1 bench dashboard -- {csv_name}</h1>
<div id="status">Loading...</div>
<table id="table"></table>
<script>
async function tick() {{
  const res = await fetch('/api/latest');
  const data = await res.json();
  document.getElementById('status').innerText =
    data.n_rows + ' rows, last at t=' + (data.latest ? data.latest.t_s.toFixed(1) : 'n/a') + 's';
  if (!data.latest) return;
  let rows = '<tr><th>field</th><th>latest</th></tr>';
  for (const k in data.latest) {{
    rows += '<tr><td>' + k + '</td><td>' + data.latest[k] + '</td></tr>';
  }}
  document.getElementById('table').innerHTML = rows;
}}
tick();
setInterval(tick, 2000);
</script>
</body>
</html>
"""


def read_latest_window(csv_path: Path, window: int = DEFAULT_WINDOW) -> dict:
    """Read the tail of csv_path. Safe to call while the file is being appended to."""
    if not csv_path.exists():
        return {"n_rows": 0, "latest": None, "window": []}

    try:
        with csv_path.open(newline="", encoding="utf-8") as f:
            rows = list(csv.DictReader(f))
    except Exception as exc:  # file mid-write / transient race
        return {"n_rows": 0, "latest": None, "window": [], "error": str(exc)}

    if not rows:
        return {"n_rows": 0, "latest": None, "window": []}

    # A `window <= 0` should mean "no history, just the latest row" -- note
    # that Python's `rows[-0:]` is `rows[0:]` (the WHOLE list), not empty,
    # so window<=0 is special-cased rather than falling through to the
    # slice below.
    tail = rows[-window:] if window > 0 else rows[-1:]

    def _coerce(row: dict) -> dict:
        out = {}
        for k, v in row.items():
            try:
                out[k] = float(v)
            except (TypeError, ValueError):
                out[k] = v
        return out

    tail_coerced = [_coerce(r) for r in tail]
    return {
        "n_rows": len(rows),
        "latest": tail_coerced[-1],
        "window": tail_coerced,
        "sparkline_fields": SPARKLINE_FIELDS,
    }


def make_handler(csv_path: Path, window: int):
    class Handler(BaseHTTPRequestHandler):
        def log_message(self, fmt, *args):  # quiet default stdout spam
            pass

        def do_GET(self):
            path = urlparse(self.path).path
            if path == "/api/latest":
                payload = json.dumps(read_latest_window(csv_path, window)).encode("utf-8")
                self.send_response(200)
                self.send_header("Content-Type", "application/json")
                self.send_header("Content-Length", str(len(payload)))
                self.end_headers()
                self.wfile.write(payload)
            elif path == "/":
                body = PAGE_TEMPLATE.format(csv_name=csv_path.name).encode("utf-8")
                self.send_response(200)
                self.send_header("Content-Type", "text/html; charset=utf-8")
                self.send_header("Content-Length", str(len(body)))
                self.end_headers()
                self.wfile.write(body)
            else:
                self.send_response(404)
                self.end_headers()

    return Handler


def serve(csv_path: Path, host: str = "127.0.0.1", port: int = 8765, window: int = DEFAULT_WINDOW):
    """Start the dashboard HTTP server. Blocks until interrupted."""
    server = ThreadingHTTPServer((host, port), make_handler(csv_path, window))
    print(f"CHORUS-SGH-1 dashboard serving {csv_path} at http://{host}:{port}/")
    try:
        server.serve_forever()
    except KeyboardInterrupt:
        pass
    finally:
        server.shutdown()
    return server


def serve_in_background(csv_path: Path, host: str = "127.0.0.1", port: int = 0, window: int = DEFAULT_WINDOW):
    """Start the server on a background thread and return (server, thread).

    port=0 lets the OS pick a free ephemeral port (used by tests); read
    it back via server.server_address[1].
    """
    server = ThreadingHTTPServer((host, port), make_handler(csv_path, window))
    thread = threading.Thread(target=server.serve_forever, daemon=True)
    thread.start()
    return server, thread


def main() -> None:
    p = argparse.ArgumentParser(description="Live dashboard for an active bench CSV")
    p.add_argument("--csv", type=Path, required=True)
    p.add_argument("--host", type=str, default="127.0.0.1")
    p.add_argument("--port", type=int, default=8765)
    p.add_argument("--window", type=int, default=DEFAULT_WINDOW)
    args = p.parse_args()
    serve(args.csv, host=args.host, port=args.port, window=args.window)


if __name__ == "__main__":
    main()

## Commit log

2026-06-01 Add device specification and acoustic layer physics docs.
    SGH-1 requirements plus AEH harvest/enhancement theory for urban and plant noise.
2026-06-01 Add acoustic harvest and ultrasonic CP enhancement models.
    Urban SPL-to-power estimates and membrane polarization helper for AEH layer analysis.
2026-06-01 Add Jupyter notebooks for physics proof and device simulation.
    End-to-end derivations and PRO/AEH sweeps linked to sizing exports.
2026-06-01 Add OpenSCAD PRO core components and shared CAD library.
    Membrane housing, manifolds, end caps, and generated sizing constants.
    [sgh1_end_cap.scad, sgh1_manifold_draw.scad, sgh1_manifold_feed.scad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]
2026-06-01 Add CHORUS frame, thermal plenum, and AEH acoustic panel CAD.
    Skid structure plus Helmholtz resonator panel and ultrasonic mount ring.
    [chorus_aeh_panel.scad, chorus_skid_enclosure.scad, sgh1_skid_frame.scad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]
2026-06-01 Add PX module, turbine housing, relief valve, and utility mounts.
    Pressure recovery path and bench safety hardware for the PRO loop.
    [sgh1_pump_mount.scad, sgh1_px_module.scad, sgh1_relief_valve_block.scad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]
2026-06-01 Add plumbing adapters, drip tray, rails, and RED v2 cartridge CAD.
    Tank interfaces and future nanopore swap-in module on shared flange pattern.
    [sgh1_brine_tank_adapter.scad, sgh1_drip_tray.scad, sgh1_feed_tank_adapter.scad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]
2026-06-01 Add full assembly and exploded-view OpenSCAD layouts.
    Installation and documentation assemblies for the complete CHORUS-SGH-1 skid.
    [sgh1_assembly.scad, sgh1_exploded_assembly.scad]
2026-06-01 Add build blueprint, BOM, materials spec, and dimensioned drawing table.
    Fabrication package with P&ID ASCII, component index, and FreeCAD import notes.
    [SGH1_BOM.csv]
2026-06-01 Add electrical wiring docs and OpenSCAD STL export script.
    DAQ sensor map and batch export pipeline for all 23 CAD parts.
2026-06-01 Add bench DAQ logger, dashboard, and serial sensor stub.
    CSV logging with simulated sensors for development before hardware integration.
2026-06-01 Add build automation scripts and sizing export artifacts.
    One-shot build_all pipeline plus sample bench logs and JSON for pdf-genesis.
    [smoke_test.csv]
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2026-06-01 Regenerate 34-page report: snappy title, OpenSCAD deep dive, full E1, BOM, patent.
2026-06-01 Anchor CHORUS math to real-world plants and regenerate paper.
    Add REAL_WORLD_DATA.md, real_world_calibration.py, Perth/Statkraft case studies,
    salinity-pair sweeps, fig12–13, and §2A in the PDF with literature-backed tables.
2026-06-10 Add T0–T1 validation stack and UDT/AOR/VOH vision layer.
    Document osmotic-vortex hydro vision, implement bench CSV validation with
    ±30% T1 gate, protocol runner, DAQ test modes, pytest suite, and notebooks
    so bench runs produce pass/fail artifacts before field outreach.
    [T1_baseline_20260609_235853.csv]
2026-06-10 Regenerate research PDF v5 with Black & White authorship and full vision stack.
    Add UDT/AOR/VOH theory sections, E14–E16 results, T0–T1c validation chapter,
    CHORUS_vision_physics notebook, and Connor White as co-author on the proposal.
2026-08-17 feat(daq): add framed ASCII serial protocol with checksum + reassembly
    Introduces daq/protocol.py: an NMEA-style checksummed sentence format
    for the DAQ-001 (Pi + MCP3008 ADC HAT) -> USB-CDC serial link implied by
    hardware/bom/SGH1_BOM.csv. Pure parsing/framing logic, unit tested
    against synthetic byte streams (split frames, garbled frames, bad
    checksums) with no hardware required.
2026-08-17 feat(daq): real pyserial ingestion with reconnect and loud fallback
    Replace the silent-passthrough stub in daq/serial_sensors.py with a
    genuine SerialLink: opens the configured --port via pyserial, decodes
    checksum-validated frames via daq/protocol.py, reconnects with backoff
    on a dropped link, and counts malformed frames instead of swallowing
    them. Simulation is used ONLY when the port cannot be opened or no
    valid frame arrives within the read timeout, and every such fallback
    raises FallbackToSimulation (RuntimeWarning) plus a stderr/log message
    -- never a silent substitution. Tested end-to-end with a fake
    serial.Serial-like object and synthetic byte streams (no real hardware
    required).
    [serial_sensors.py]
2026-08-17 feat(simulation): constant-calibration pipeline for L_p and RPM->torque
    Adds scripts/calibrate_constants.py: fits membrane permeability L_p
    from bench CSV steady-state windows (reusing simulation.bench_validation)
    and an RPM->torque coefficient via origin-forced OLS on
    (omega_rpm, P_spin_motor_W) samples. Runs today against the existing
    simulated CSVs in data/bench/ and labels every result's data_provenance
    explicitly (simulated / synthetic_demo_in_memory / real via a
    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
2026-08-17 feat(scripts): CAD geometry manifold/watertightness check in audit_openscad
    Adds scripts/stl_check.py: a dependency-free binary-STL checker
    (triangle count, degenerate-triangle detection, edge-pairing
    watertightness) and wires it into scripts/audit_openscad.py, which now
    shells out to the openscad CLI per part (--export-format=binstl) when
    available. This dev environment has no openscad binary installed
    (confirmed via shutil.which), so every part's geometry_check records an
    explicit 'skipped: openscad binary not found on PATH' reason instead of
    a silent or fabricated pass -- the audit JSON surfaces
    openscad_binary_found: false and a top-level gap note. Render failures
    (bad geometry, timeout)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
2026-08-17 feat(daq): lightweight stdlib live dashboard for bench sessions
    Adds daq/dashboard.py: a ThreadingHTTPServer-based (stdlib only, no
    Flask/websocket dependency added) viewer that tails an active bench
    CSV and serves /api/latest (JSON) plus a polling HTML page. Lets a
    bench operator watch a running T0-T2 session without waiting for it to
    finish. Tested end-to-end against a real ephemeral-port server hitting
    both endpoints with urllib.
2026-08-17 feat(daq): wire up vision-stack sensor protocol () and multiplexed reads
    Adds a second sentence type to daq/protocol.py () for the
    acoustic/vortex vision stack (AEH-003 28kHz ultrasonic transducer +
    AEH-002 PVDF piezo array per hardware/bom/SGH1_BOM.csv), sharing the
    same checksum/framing scheme and multiplexed on one serial link with
    the existing process-sensor sentence. parse_any() dispatches on
    sentence id; StreamReassembler now yields both types.
    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
2026-08-17 docs: refresh roadmap status table and README usage after full implementation
    All roadmap items land as fully implemented and tested in this branch
    except three explicitly-documented hard hardware limits (M6 real bench
    data, M7b real transducer/piezo data, M8 hardware-in-the-loop run) --
    none of which can be satisfied without a physical CHORUS-SGH-1 skid.
    M3's code path (openscad CLI + STL manifold checker) is complete; only
    the openscad binary itself is absent in this environment. README now
    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
2026-08-17 feat(simulation): vision-stack signal processing (RMS amplitude, phase coherence, eta_tink estimate)
    Adds simulation/vision_signal.py: turns a stream of $SGHV samples into
    the quantities the UDT/AOR/VOH math actually consumes -- windowed
    RMS/envelope amplitude, circular-statistics phase coherence (resultant
    vector length R over us_phase_deg), and an eta_tink coupling-efficiency
    estimate bridging to simulation.differential_tink. RollingVisionProcessor
    maintains a fixed-size window for streaming use against
    daq.serial_sensors.read_vision_sensors_serial output. This closes the
    round-1 gap where $SGHV protocol/framing existed but nothing downstream
    interpreted the samples as a signal. Tested aga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
2026-08-17 fix(daq): dashboard window=0 boundary bug; test concurrency/race/malformed-field paths
    Fixes a real bug: read_latest_window(window=0) previously returned the
    ENTIRE CSV because Python's rows[-0:] is rows[0:], not an empty slice.
    window<=0 is now special-cased to mean 'no history, just the latest
    row'. Adds tests for the actual operating condition round 1 didn't
    cover: a CSV being actively appended to while concurrently served (40
    concurrent GETs against a live writer thread), a truncated/partially-
    flushed last line, malformed non-numeric fields (falls back to the raw
    string rather than crashing), and window-larger-than-file-size.
    [dashboard.py]
2026-08-17 feat(scripts): multi-run aggregate L_p calibration with CI and robust outlier detection
    Adds fit_L_p_aggregate() to calibrate_constants.py: fits L_p per bench
    CSV across multiple runs and reports mean, sample std, a
    scipy.stats.t-based confidence interval, and outlier-run flags. Outlier
    detection uses median + MAD (robust z-score, Iglewicz & Hoaglin 1993)
    rather than mean/std, because a naive z-score masks the very outlier
    that inflated the std in small-n samples -- verified against a
    synthetic fixture where the naive approach failed to flag an
    obviously-wrong run and the MAD approach caught it. New --aggregate /
    --confidence CLI flags. Tested with clustered-runs, single-run
    (zero-width CI),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
2026-08-17 feat(scripts): protocol-run history CLI
    Adds scripts/protocol_history.py: scans data/bench/*/checkpoint.json +
    manifest.json + bench_validation.json and renders a table (or --json)
    of test id, completed steps, pass/fail, and run count -- closing the
    round-1 gap where checkpoint.json was only ever consumed by
    run_test_protocol.py itself, so answering 'which bench sessions have I
    completed and did they pass' meant manually grepping JSON files.
    Supports --test-id filtering. Tested against synthetic checkpoint/
    manifest/validation fixtures.
2026-08-17 feat(scripts): STL winding-consistency check and ASCII-STL rejection
    Extends scripts/stl_check.py with two round-2 defect classes edge-
    pairing alone misses: (1) directed-edge winding-consistency detection
    -- a mesh can be edge-paired 'closed' yet still have two faces sharing
    an edge in the SAME direction (flipped/inconsistent normals), which a
    naive undirected edge count reports as watertight when it is not a
    true orientable manifold; (2) explicit ASCII-STL header sniffing so a
    misconfigured export produces a specific 'looks like ASCII, not
    binary' error instead of a generic too-small/truncated failure.
    audit_openscad.py's geometry_check now surfaces
    inconsistent_winding_edges per part. Tes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
2026-08-17 docs: add ENVIRONMENTAL_IMPACT.md with real brine-discharge ecology and permitting precedent
    Cites documented ecological concerns (hypersalinity/density
    stratification, benthic stress, chemical additives) and real
    regulatory precedent (California's Desalination Amendment, Perth
    PSDP2's environmental referral process), using the Carlsbad plant's
    documented permit-limit exceedance as a concrete real example rather
    than a hypothetical. States plainly that CHORUS-SGH-1's own
    dilution-reduces-impact hypothesis is untested (no published PRO
    dilution-benefit study was found) and that no PRO/RED-specific
    environmental permitting precedent exists -- honest gaps, not filled
    in with invented claims.
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2026-08-18 docs: add round-4 roadmap and implementation plan
    Round 3 found CHORUS-SGH-1's best case (~$2/kWh) is 22-75x more
    expensive than solar/wind. Round 4 attacks that gap directly: breakeven
    sensitivity solvers (what parameter, changed how much, closes it),
    manufacturing learning-curve cost projection, and honest avoided-cost
    co-benefit framing -- allowed to conclude 'no plausible path' if that
    is what the model actually shows.
2026-08-18 feat(scripts): breakeven sensitivity solvers for LCOE gap-closing analysis
    Adds solve_breakeven_power_density/_membrane_cost/_membrane_life to
    scripts/lcoe_model.py: bisection root-finders answering 'what single
    parameter value, holding everything else fixed, reaches a target LCOE'
    -- each checked against a real physical/practical ceiling
    (docs/math/REAL_WORLD_DATA.md's 60 W/m^2 lab-hypersaline density
    ceiling, a $0/m^2 cost floor, a 15-year industrial RO/FO membrane life
    ceiling) rather than reporting a bare number.
    Real finding: reaching Lazard's solar/wind upper bound ($0.09/kWh) is
    UNREACHABLE via any single lever (power density, membrane cost, or
    membrane life) within known ceilings --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
2026-08-18 feat(scripts): avoided-T&D co-benefit credit + CLI wiring for breakeven/learning-curve/co-benefit
    Adds co_benefit_adjusted_lcoe(): applies a real, cited avoided
    transmission-and-distribution credit (~$0.02/kWh, from utility
    avoided-cost studies) as a partial offset against the raw LCOE --
    reported honestly as a small percentage of a multi-dollar/kWh raw
    number, never presented as closing the underlying capex-driven gap.
    Also clarifies in the docstring that the 'brine is already flowing,
    fuel is free' argument is already fully reflected in compute_lcoe
    (no fuel cost line item exists anywhere in the model), so it is not a
    second, separately-creditable co-benefit.
    Wires --breakeven/--learning-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
2026-08-18 feat(lcoe): add one-at-a-time LCOE sensitivity tornado analysis
    Adds tornado_sensitivity() to scripts/lcoe_model.py, sweeping each cost
    lever (membrane cost, BOP cost, membrane replacement interval, areal
    power density) independently across its own honest low/high anchor
    while holding all others at baseline, to isolate which single parameter
    moves LCOE the most (unlike sensitivity_sweep's combined bundles).
    Wires up a --tornado CLI flag and exports the result to
    exports/lcoe_tornado.json.
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
